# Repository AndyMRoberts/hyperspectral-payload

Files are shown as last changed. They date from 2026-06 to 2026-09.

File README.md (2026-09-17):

# Hyperspectral Payload

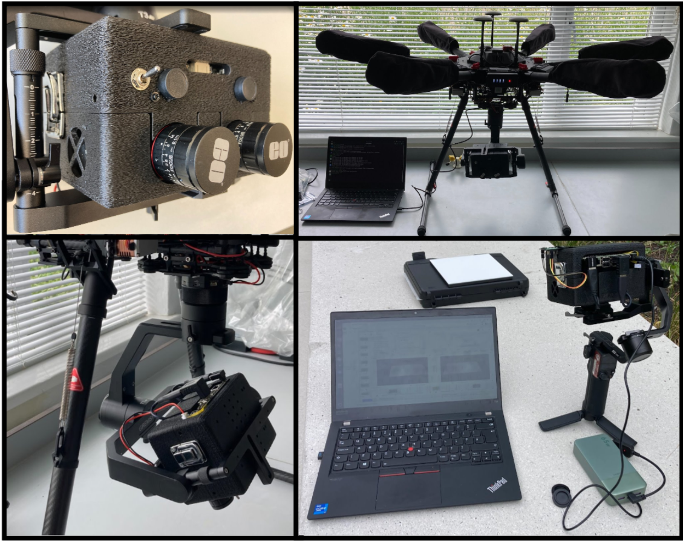
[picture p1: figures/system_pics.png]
System overview


# Folder Structure

```
hyperspectral-payload/
├── 3D_models/              CAD models (STL) for the payload enclosure and sensor mounts.
├── calibration_files/      Used by some of the test code in private_repo, not necessary for running but there as an example of the folder structure created during a run. 
├── figures/                Documentation images, including the system overview photo.
├── foxglove/               Foxglove Studio layout configs and generator for live ROS visualization.
├── private_repo/           Git submodule for development code
├── processing/             Offline Jupyter notebooks for post-run HSI data analysis.
└── ros2_ws/                Main ROS 2 workspace — onboard drivers, processing, and launch files.
    └── scripts/            Currently scripts for downloading and configuring extra ros2 nodes.
    └── src/
        ├── bringup/        Top-level launch files that start cameras, previews, and related nodes.
        │   └── hsi_bringup/
        ├── common/         Shared Python utilities used across HSI packages.
        │   └── hsi_python_utils/
        ├── controller/     System-level controller nodes for coordinating the platform.
        │   └── hsi_system_controller/
        ├── custom_msgs/    Custom ros2 messages e.g. hyperspectral data cube
        ├── monitoring/     Onboard power and memory usage monitoring.
        │   └── system_profiler/
        ├── processing/     Real-time image processing pipelines.
        │   ├── hsi_binned_preview_cpp/     Downsampled max/avg/colour previews for HSI streams.
        │   ├── radiometric_processing/       IN DEVELOPMENT: online fast radiometric processing in python
        │   ├── radiometric_processing_cpp/   IN DEVELOPMENT: online fast radiometric processing in cpp
        │   └── stereo_binned_preview_cpp/    Stereo rectification, disparity, and binned previews.
        └── sensors/        Hardware drivers for all payload sensors.
            ├── gps_monitor_cpp/              DFRobot USB GPS receiver — publishes NavSatFix.
            ├── hsi_camera_driver_cpp/        IMEC mosaic hyperspectral camera driver (VIS and NIR).
            ├── imu/                          IMU on the Waveshare stereo camera board (I2C).
            ├── spectrometer/                 AS7341 spectrometer — publishes spectral curves.
            └── stereo_camera/                IMX219 stereo camera — raw left/right image streams.
```

# ROS 2 workspace

## Intro

This repo is a working progress for the open source hyperspectral payload project, it includes all code and 3d prints necessary for reproducing and running the payload. Note that the system relies on having the specific MQ022HG-IM-SM4X4-VIS3 & MQ022HG-IM-SM5X5-NIR2 Ximea XiSpec hyperspectral sensors and IMEC API for grabbing/processing. 

### Dependencies
- IMEC API (provided with Ximea XiSpec camera purchase)
- ROS2 Humble distro (https://docs.ros.org/en/humble/index.html)
- Tested on Jetson Orin Nano running Jetpack 6.2.1

### Setup
1. Clone repo to the Jetson Nano and install dependencies.
1. From \ros2_ws run:

```
source /opt/ros/humble/setup.bash
colcon build
source install/setup.sh
```

1. 3D print case parts and add screw inserts x4.
1. Install hardware into case.
1. Connect Jetson to the same wifi network as the remote PC, can be a wifi hotspot generated from a laptop.
1. Import the foxglove layout file (master_layout.json) to either the web or desktop version of the foxglove UI on the remote PC, connect to the IP address of the Jetson. 
1. SSH to the Jetson and from \ros2_ws launch system with full system launch command, this will also launch the foxglove bridge to allow communication with foxglove UI over the network.

'ros2 launch hsi_bringup full_system.launch.py run_name:=default_run_name acquisition_rate_hz:=20.0 throttled_rate_hz:=20.0'

### General Overview
- SSH onto the device from field laptop.
- Use a launch file to launch the desired nodes with the desired settings.
- Via the Foxglove interface you can view the output data and send conrol messages to the system, such as for recording reference images, initiating timelapses, stopping, and shutting down. 
- Reference images are collected first using the foxglove interface. 
- Once ready a timelapse can be started, this records the hyperspectral images using the imec_api, and all other sensor data via a rosbag of the relevant topics.
- Once done, stop the recording via the foxglove interface stop button(rosbag will be corrupt if not shutdown properly), then shutdown the ros system from the UI, as well as killing any remaining nodes with 'ctrl + c' from the launch terminal. 
- Safely shutdown the jetson using 'sudo shutdown now'.

### Configurations
- Rosbag recording topics: in order to reduce memory usage the rosbag topic list can be shortened via the exclusion list in camera_commands_controller.py.
- Nodes: nodes can be excluded from launch if not required via the hsi_bringup full_system.launch.py file.
- 

### Example Launch Commands
```
# Run full system with legacy stereo (not issac argus node), with only left camera recording, no live radiometric processing, hsi cameras acquiring at 20hz, rosbag saving at 20Hz:
ros2 launch hsi_bringup full_system.launch.py run_name:=run_name_here acquisition_rate_hz:=20.0 throttled_rate_hz:=20.0 use_legacy_stereo:=True single_stereo_mode:=True enable_online_radiometric_proc:=False

# Same as above but with under development isaac argus node running for the stereo recording and processing:
ros2 launch hsi_bringup full_system.launch.py run_name:=test acquisition_rate_hz:=20.0 throttled_rate_hz:=20.0 enable_online_radiometric_proc:=False

# For runnign stereo cameras only:
ros2 launch hsi_bringup stereo_only.launch.py run_name:=stereo_rate_testing use_legacy_stereo:=True single_stereo_mode:=True

```

### Data Collection Procedure

From the foxglove UI you need to set the integration times, and record calibration images using the buttons and message send options. An example of the interface is shown below:

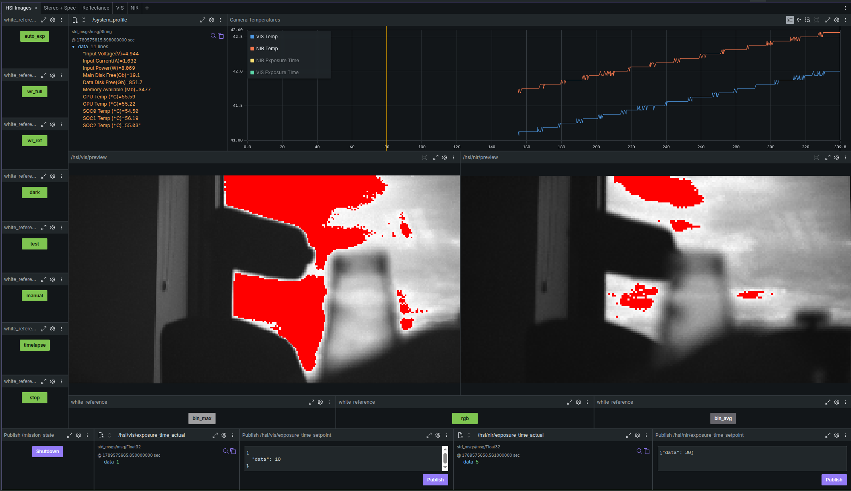
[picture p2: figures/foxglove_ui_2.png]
Foxglove UI


The visible image is in the left panel with nir in the right. The camera sensor temperatures are displayed in the top right panel, these should be stable before recording a session to prevent thermal drift effects in the sensors. The other_sensors tab will show the RGB stereo images and resulting depth image, as well as other sensor outputs like gps. 

1. Remove lens caps set F#, focus with the hyperspectral cameras, higher F#'s allow a greater Field Of View and hence more reliable imaging. 

1. The buttons down the left side are roughly followed from top to bottom:
- auto_exp - this will "reduce" the exposure/integration times of both sensors until no overexposure is imaged, the hsi image panels will show a grayscale image with red for overexposure to check. The exposure can be set manually using the data send panels along the bottom, by changing the int value after {"data": 10} and clicking the publish button. 
- wr_full - records a non-uniformity white reference in which the white reference panel should fill the full image. 
- wr_ref - records a reference white reference, an image that has the white reference in view but does not fill the full sensor. 
- dark - records a dark reference image. Lens caps should be placed on the sensors before taking this.
- test - records a test image that will be saved in the context folder. 
- manual - records a manual image that will be saved in the timelapse folder but will be titled "manual_#.raw".
- timelapse - triggers the timelapse recording at the configuration set at launch. 
- stop - stops the timelapse recording. 
- shutdown - triggers a graceful shutdown of the system. 

### Post Processing 

Once a run has been completed the raw hyperpectral images can be radiometrically processed and the rosbag unpacked using post_run_data_processing.ipynb.

# Other

## Build

From /ros2_ws directory:

```bash
source /opt/ros/humble/setup.bash
colcon build --symlink-install
source install/setup.bash
```

### Serial port permissions

The GPS receiver connects over USB serial (default `/dev/ttyACM0`). Without access to that device, `gps_monitor_cpp` fails with `open serial port: Permission denied`.

Do **not** run the node with `sudo` — that breaks ROS networking. Add your user to the `dialout` group instead (requires admin/sudo once):

```bash
sudo usermod -aG dialout $USER
```

Log out and log back in (or reboot), then verify:

```bash
groups                    # should list dialout
ls -la /dev/ttyACM0
ros2 run gps_monitor_cpp gps_monitor
```

To test in the current shell without logging out:

```bash
newgrp dialout
ros2 run gps_monitor_cpp gps_monitor
```

If you do not have sudo access, ask a system administrator to run `sudo usermod -aG dialout <username>` for you.

## GPS monitor

Publishes `sensor_msgs/NavSatFix` on `/sensors/gps` from the DFRobot USB GPS receiver:

```bash
source install/setup.bash
ros2 run gps_monitor_cpp gps_monitor
```

Override the serial port if needed:

```bash
ros2 run gps_monitor_cpp gps_monitor --ros-args -p serial_port:=/dev/ttyACM0
```

To print raw parsed GPS data (via `printf`) and publish `NavSatFix` even without a satellite fix:

```bash
ros2 run gps_monitor_cpp gps_monitor --ros-args -p publish_invalid:=true
```

See [Serial port permissions](#serial-port-permissions) if the node cannot open the device.

# Waveshare IMX219-83 Stereo Camera and IMU

Required to run this on Jetson Orin Nano: 

`sudo /opt/nvidia/jetson-io/jetson-io.py`

and configure for "Configure Jetson 24pin CSI Connector" >> "Configure for IMX219 Dual"

Demo code can be downloaded to ros2_ws/src/sensors/stereo_camera

```
wget https://files.waveshare.com/upload/e/eb/D219-9dof.tar.gz
tar zxvf D219-9dof.tar.gz
```

Other support here: https://www.waveshare.com/wiki/IMX219-83_Stereo_Camera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

For IMU use,respectively connect the SDA and SCL pins of the camera to pins 3 and 5
on the Jetson Nano.

# Spectrometer

Installs
```
sudo apt-get update
sudo apt-get install python3-pip i2c-tools libgpiod-dev
pip3 install Adafruit-Blinka adafruit-circuitpython-as7341
sudo usermod -aG i2c $USER
```

For testing:
```
export JETSON_MODEL_NAME=JETSON_ORIN_NANO
python3 spectrometer_test.py
```

# IMU

On pins 3 and 5 IMU shows up as addres 0x68 on i2c_7
`sudo i2cdetect -y -r 7`

## IMEC mosaic Python API — `LoadOpticalSetup` ctypes fix

`post_run_data_processing.ipynb` (and any code that calls `HSI_MOSAIC.LoadOpticalSetup()`) can fail with:

```text
ArgumentError: argument 1: TypeError: wrong type
```

This is **not** a missing file or UTF-8 encoding problem. The C API takes `char const*`, but the Python wrapper declares `ctypes.c_wchar_p` (expects a `str`) while passing `filename.encode('utf-8')` (`bytes`). ctypes rejects the argument before the DLL reads the XML.

**Fix** in `/opt/imec/hsi-mosaic/python_apis/hsi_mosaic/hsi_mosaic_api.py` (around the `mosaicLoadOpticalSetup` binding, line 487):

```python
# Before (broken):
__api_dll.mosaicLoadOpticalSetup.argtypes = [ctypes.c_wchar_p, ctypes.POINTER(OpticalSetup)]

# After (matches LoadContext and char const*):
__api_dll.mosaicLoadOpticalSetup.argtypes = [ctypes.c_char_p, ctypes.POINTER(OpticalSetup)]
```

Leave the call unchanged:

```python
result = __api_dll.mosaicLoadOpticalSetup(filename.encode('utf-8'), ctypes.byref(optical_setup))
```

Restart the Jupyter kernel (or re-import `hsi_mosaic`) after editing. This patch is overwritten if the IME SDK is reinstalled or upgraded.

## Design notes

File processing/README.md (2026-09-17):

# Post-Processing Scripts

## post_run_data_processing.ipynb
- runs on jetson (required for ros environment for rosbag unpacking)
- uses HSI_MOSAIC api to radiometrically process the HSI images and outputs some inspected images (see below)

Example Output:
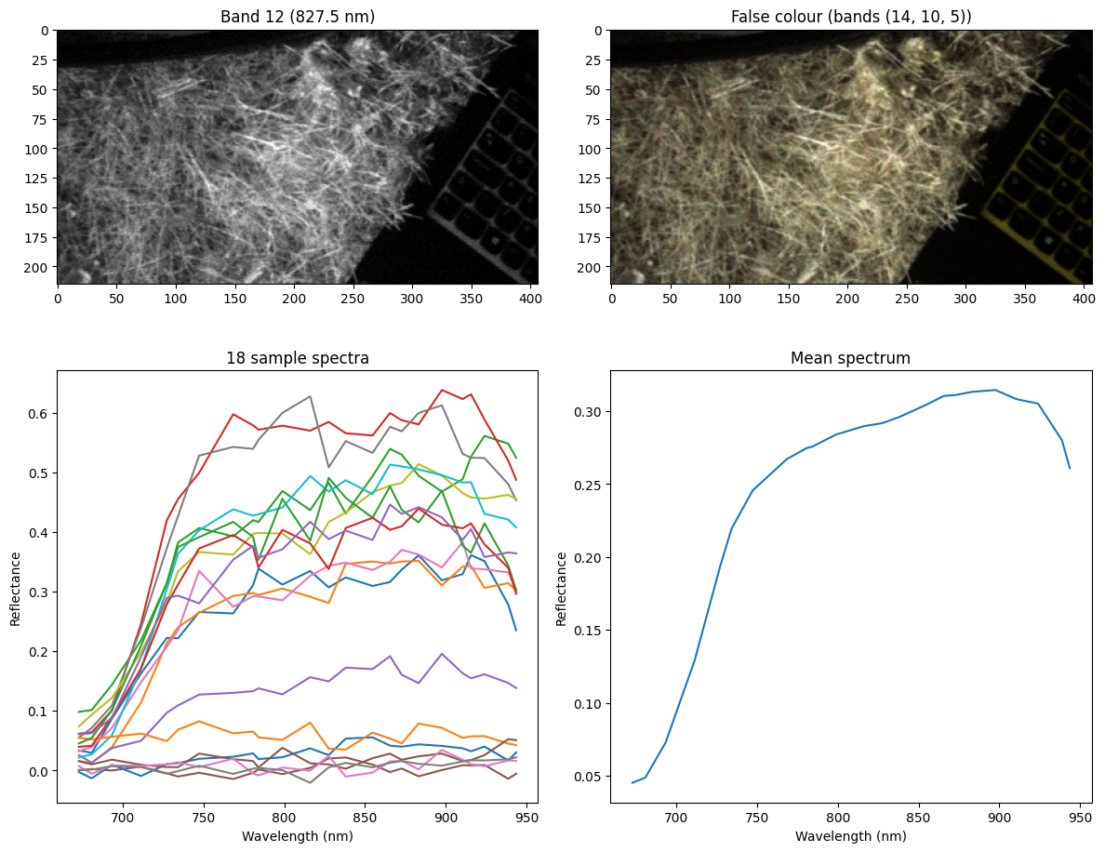
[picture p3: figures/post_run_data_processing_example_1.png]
Example Output


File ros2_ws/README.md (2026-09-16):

# ROS 2 workspace

## Todo
1. stereo camera needs hardware sync adding, then recalibration
2. Eventually if other sensors are required, change from HSI API to custom implementation in order to be able to record everything in a rosbag to be able to have synced data between HSI and everything else. 

## Clone

For others cloning this repo: after a normal clone, initialize submodules with:

```bash
git submodule update --init --recursive
```

Or clone in one step:

```bash
git clone --recurse-submodules <your-repo-url>
```

### USB_GPS_EN submodule: required `gps.h` patches

The `gps_monitor_cpp` package vendors [DFRobotdl/USB_GPS_EN](https://github.com/DFRobotdl/USB_GPS_EN) as a git submodule. After initializing submodules, apply these manual edits to:

`src/sensors/gps_monitor_cpp/include/USB_GPS_EN/gps.h`

Inside `parse_GpsDATA()`, in the `switch (i)` block:

1. **Comment out line 62** — the `buffer` variable is unused and triggers a compiler warning:

```c
// char buffer[12];
```

2. **Add `break;` statements** so that every `memcpy` in the switch ends with `break;` (lines 72 and 76 in the patched file; upstream is also missing breaks after the case 3 and case 5 `memcpy` calls). The corrected switch body should look like:

```c
switch(i){
  case 1:RST_Buffer(Save_Data.UTCTime);
    memcpy(Save_Data.UTCTime, subString, subStringNext - subString);break;
  case 2:RST_Buffer(usefullBuffer);
    memcpy(usefullBuffer, subString, subStringNext - subString);break;
  case 3:RST_Buffer(Save_Data.Slatitude);
    memcpy(Save_Data.Slatitude, subString, subStringNext - subString);break;
  case 4:RST_Buffer(Save_Data.N_S);
    memcpy(Save_Data.N_S, subString, subStringNext - subString);break;//获取 N/S
  case 5:RST_Buffer(Save_Data.Slongitude);
    memcpy(Save_Data.Slongitude, subString, subStringNext - subString);break;
  case 6:RST_Buffer(Save_Data.E_W);
    memcpy(Save_Data.E_W, subString, subStringNext - subString);break;//获取 E/W
  default:break;
}
```

Without these `break` statements, cases fall through and latitude/longitude parsing is corrupted.

### Serial port permissions

The GPS receiver connects over USB serial (default `/dev/ttyACM0`). Without access to that device, `gps_monitor_cpp` fails with `open serial port: Permission denied`.

Do **not** run the node with `sudo` — that breaks ROS networking. Add your user to the `dialout` group instead (requires admin/sudo once):

```bash
sudo usermod -aG dialout $USER
```

Log out and log back in (or reboot), then verify:

```bash
groups                    # should list dialout
ls -la /dev/ttyACM0
ros2 run gps_monitor_cpp gps_monitor
```

To test in the current shell without logging out:

```bash
newgrp dialout
ros2 run gps_monitor_cpp gps_monitor
```

If you do not have sudo access, ask a system administrator to run `sudo usermod -aG dialout <username>` for you.

## Build

From this directory:

```bash
source /opt/ros/$ROS_DISTRO/setup.bash
colcon build --symlink-install
source install/setup.bash
```

## GPS monitor

Publishes `sensor_msgs/NavSatFix` on `/sensors/gps` from the DFRobot USB GPS receiver:

```bash
source install/setup.bash
ros2 run gps_monitor_cpp gps_monitor
```

Override the serial port if needed:

```bash
ros2 run gps_monitor_cpp gps_monitor --ros-args -p serial_port:=/dev/ttyACM0
```

To print raw parsed GPS data (via `printf`) and publish `NavSatFix` even without a satellite fix:

```bash
ros2 run gps_monitor_cpp gps_monitor --ros-args -p publish_invalid:=true
```

See [Serial port permissions](#serial-port-permissions) if the node cannot open the device.

## Bringup: HSI cameras and binned preview

Launches the VIS and NIR `hsi_camera_driver_cpp` nodes and the `hsi_binned_preview_cpp` preview node:

```bash
source install/setup.bash
ros2 launch hsi_bringup hsi_cameras_with_binned_preview.launch.py
```

or for multicam
```bash
source install/setup.bash
ros2 launch hsi_bringup hsi_cameras_multicam_binned_preview.launch.py
```

# Waveshare IMX219-83 Stereo Camera and IMU

Required to run this on Jetson Orin Nano: 

`sudo /opt/nvidia/jetson-io/jetson-io.py`

and configure for "Configure Jetson 24pin CSI Connector" >> "Configure for IMX219 Dual"

## Isaac ROS Argus stereo (recommended)

Stereo capture is provided by [`isaac_ros_argus_camera`](https://github.com/NVIDIA-ISAAC-ROS/isaac_ros_argus_camera) (Isaac ROS **release-3.2**, matching JetPack 6.x / Humble) inside the Isaac Dev Docker container. Host bringup keeps HSI/GPS/etc. on the host and expects Argus to publish:

- `/sensors/stereo/left`
- `/sensors/stereo/right`

(`left/image_raw` / `right/image_raw` remapped by `argus_stereo.launch.py`)

### One-time host prerequisites (sudo)

Rootfs is small; Docker **and containerd** data must live on `/mnt/data` (Isaac pulls otherwise fill `/var/lib/containerd` on eMMC):

```bash
bash ros2_ws/scripts/setup_isaac_docker_prereqs.sh
```

Then **log out and back in** (or `newgrp docker`) and verify:

```bash
docker ps
git lfs version
df -h /
```

If the container fails with `unresolvable CDI devices nvidia.com/gpu=all`, `run_dev.sh` is patched to use `NVIDIA_VISIBLE_DEVICES=all`. Optional CDI generate:

```bash
sudo nvidia-ctk cdi generate --output=/etc/cdi/nvidia.yaml
```

Repos are already cloned under `ros2_ws/src/isaac_ros_common` and `ros2_ws/src/isaac_ros_argus_camera` (branch `release-3.2`). Host `colcon build` skips them via `COLCON_IGNORE` in those trees.

### Two-terminal workflow

**Terminal A — Isaac Docker (Argus):**

```bash
cd /home/hyper/hyperspectral_camera/ros2_ws
./scripts/run_isaac_dev.sh
# inside container only:
./scripts/build_isaac_argus.sh
source /opt/ros/humble/setup.bash
ros2 launch /workspaces/isaac_ros-dev/src/bringup/hsi_bringup/launch/argus_stereo.launch.py
```

Notes:
- `build_isaac_argus.sh` installs apt package `ros-humble-isaac-ros-argus-camera`.
- Do **not** `source install/setup.bash` inside the container — that tree was built on the host with paths under `/home/hyper/...`, which break under `/workspaces/...`.
- Launch the remapped file by **absolute path** (no need to colcon-build `hsi_bringup` in Docker).

**Terminal B — host (rest of system):**

```bash
cd /home/hyper/hyperspectral_camera/ros2_ws
source /opt/ros/humble/setup.bash
source install/setup.bash
ros2 launch hsi_bringup full_system.launch.py run_name:=test
# or stereo-focused:
ros2 launch hsi_bringup stereo_only.launch.py run_name:=test
```

By default `use_legacy_stereo:=false` so the host does **not** start the OpenCV `stereo_camera` node.

### Legacy OpenCV stereo fallback

```bash
ros2 launch hsi_bringup full_system.launch.py use_legacy_stereo:=true
```

### Camera daemon

If Argus fails to open the sensor:

```bash
sudo systemctl restart nvargus-daemon.service
```

---

## Legacy OpenCV stereo notes

Demo code can be downloaded to ros2_ws/src/sensors/stereo_camera

```
wget https://files.waveshare.com/upload/e/eb/D219-9dof.tar.gz
tar zxvf D219-9dof.tar.gz
```

Other support here: https://www.waveshare.com/wiki/IMX219-83_Stereo_Camera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

For IMU use,respectively connect the SDA and SCL pins of the camera to pins 3 and 5
on the Jetson Nano.

To fix image looking overly red (from link):
```
wget https://files.waveshare.com/upload/e/eb/Camera_overrides.tar.gz
tar zxvf Camera_overrides.tar.gz 
sudo cp camera_overrides.isp /var/nvidia/nvcam/settings/
sudo chmod 664 /var/nvidia/nvcam/settings/camera_overrides.isp
sudo chown root:root /var/nvidia/nvcam/settings/camera_overrides.isp
```

# Spectrometer

Installs
```
sudo apt-get update
sudo apt-get install python3-pip i2c-tools libgpiod-dev
pip3 install Adafruit-Blinka adafruit-circuitpython-as7341
sudo usermod -aG i2c $USER
```

For testing:
```
export JETSON_MODEL_NAME=JETSON_ORIN_NANO
python3 spectrometer_test.py
```

# IMU

On pins 3 and 5 IMU shows up as addres 0x68 on i2c_7
`sudo i2cdetect -y -r 7`

## IMEC mosaic Python API — `LoadOpticalSetup` ctypes fix

`post_run_data_processing.ipynb` (and any code that calls `HSI_MOSAIC.LoadOpticalSetup()`) can fail with:

```text
ArgumentError: argument 1: TypeError: wrong type
```

This is **not** a missing file or UTF-8 encoding problem. The C API takes `char const*`, but the Python wrapper declares `ctypes.c_wchar_p` (expects a `str`) while passing `filename.encode('utf-8')` (`bytes`). ctypes rejects the argument before the DLL reads the XML.

**Fix** in `/opt/imec/hsi-mosaic/python_apis/hsi_mosaic/hsi_mosaic_api.py` (around the `mosaicLoadOpticalSetup` binding, line 487):

```python
# Before (broken):
__api_dll.mosaicLoadOpticalSetup.argtypes = [ctypes.c_wchar_p, ctypes.POINTER(OpticalSetup)]

# After (matches LoadContext and char const*):
__api_dll.mosaicLoadOpticalSetup.argtypes = [ctypes.c_char_p, ctypes.POINTER(OpticalSetup)]
```

Leave the call unchanged:

```python
result = __api_dll.mosaicLoadOpticalSetup(filename.encode('utf-8'), ctypes.byref(optical_setup))
```

Restart the Jupyter kernel (or re-import `hsi_mosaic`) after editing. This patch is overwritten if the IME SDK is reinstalled or upgraded.

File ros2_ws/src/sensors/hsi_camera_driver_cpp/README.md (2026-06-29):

# hsi_camera_driver_cpp

ROS 2 Humble C++ node for HSI camera acquisition using the imec Camera API.

## Build

```bash
cd /home/hyper/hyperspectral_camera/ros2_ws
colcon build --packages-select hsi_camera_driver_cpp --symlink-install
source install/setup.bash
```

## Run

### Basic run

```bash
ros2 run hsi_camera_driver_cpp hsi_camera_node
```

### Run with parameters (free-run)

```bash
ros2 run hsi_camera_driver_cpp hsi_camera_node \
  --ros-args \
  -p free_run:=true \
  -p timelapse_hz:=1.0 \
  -p rate_hz:=20.0 \
  -p device_name:=nir \
  -p exposure_time_ms:=20.0 \
  -p gain:=1.0 \
  -p test_frame_count:=-1 \
  -p run_name_path:=/mnt/data/timelapses/20260101_120000_test_commands
```

### Run with parameters (fixed-rate software trigger)

```bash
ros2 run hsi_camera_driver_cpp hsi_camera_node \
  --ros-args \
  -p free_run:=false \
  -p rate_hz:=5.0 \
  -p device_name:=nir \
  -p exposure_time_ms:=10.0 \
  -p gain:=1.0 \
  -p test_frame_count:=100

```

## Parameters

- `free_run` (`bool`, default: `true`): free-running acquisition mode.
- `rate_hz` (`double`, default: `20.0`): loop rate used when `free_run:=false`.
- `device_name` (`string`, default: `""`): camera selector (`vis`, `nir`, or empty for first detected camera).
- `exposure_time_ms` (`double`, default: `10.0`): camera exposure time.
- `gain` (`double`, default: `1.0`): camera gain.
- `test_frame_count` (`int`, default: `-1`): if non-negative, stops after that many frames and prints elapsed time/FPS.
- `camera_start_delay_ms` (`int`, default: `0`): if positive, sleeps that many milliseconds immediately before `cameraStart()` (useful to stagger two nodes on the same USB bus).

## Launch both cameras

```bash
ros2 launch hsi_camera_driver_cpp hsi_dual_camera.launch.py
```

This launch file starts two node instances:
- VIS camera node with `device_name:=vis` and `camera_start_delay_ms:=0`
- NIR camera node with `device_name:=nir` and `camera_start_delay_ms:=2500` (starts streaming slightly later to reduce USB contention)

## Published Topics

- `/hsi/<device_name>/raw_image` (`sensor_msgs/msg/Image`)
- `/hsi/<device_name>/raw_metadata` (`std_msgs/msg/String`)
- `/hsi/<device_name>/temp` (`std_msgs/msg/Float32`)

## Notes

- The node links against imec SDK libraries in `/opt/imec/hsi-mosaic/bin`.
- If your shell cannot find those shared libraries at runtime, set:

```bash
export LD_LIBRARY_PATH=/opt/imec/hsi-mosaic/bin:$LD_LIBRARY_PATH
```

- once publishing enabled the rate is throttled to about 25Hz

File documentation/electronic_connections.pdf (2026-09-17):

## Electronics

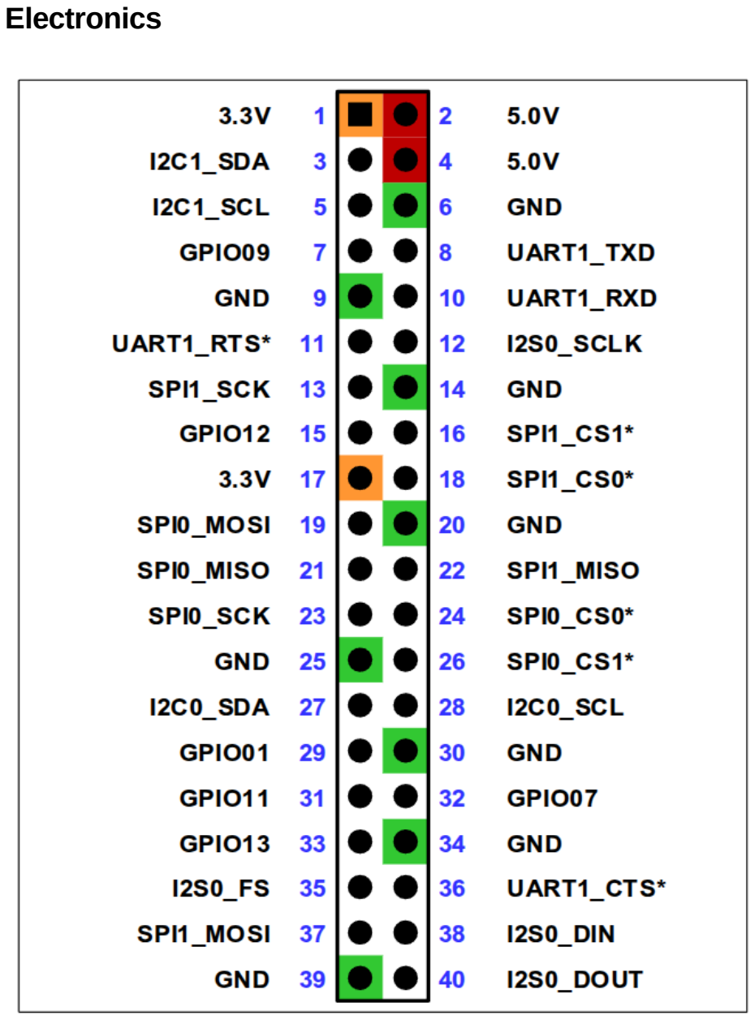
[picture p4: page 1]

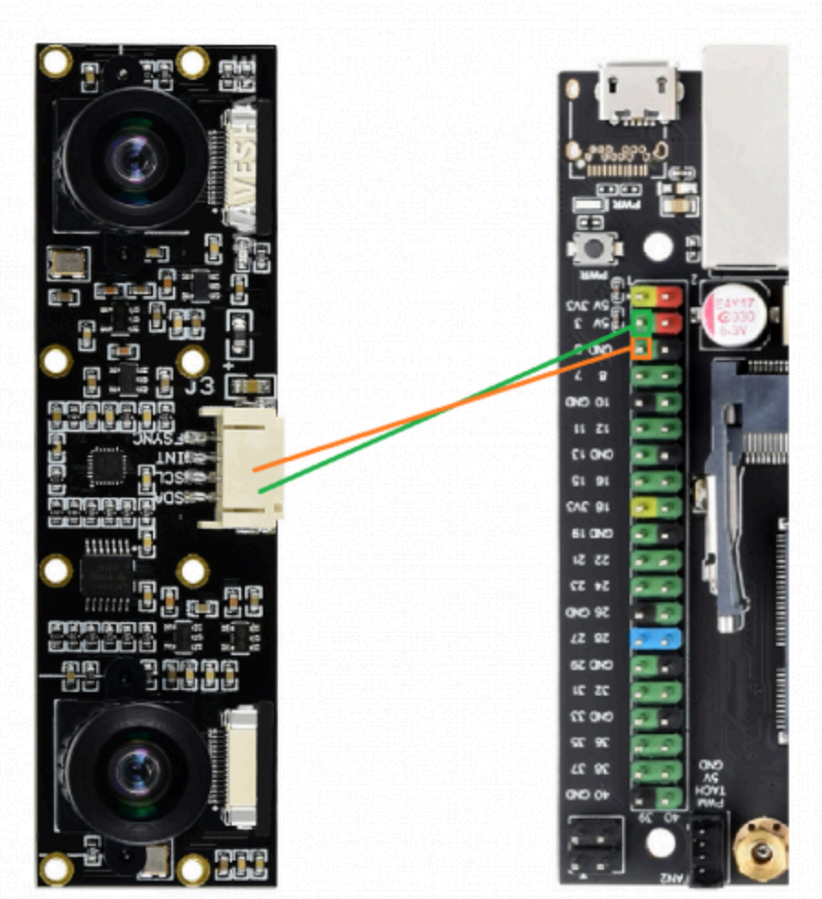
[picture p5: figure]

Mikroe: https://www.mikroe.com/spectrometer-click?srsltid=AfmBOoq2WCiolWs3EBrGVhS9cOvY8pOKp8dyzJ-nhC9IxcjtML4PU1Ps (https://www.mikroe.com/spectrometer-click)

Pin | Name | Notes | Use in Hyper
1 | 3.3V | Power (3.3V rail) | mikroe +
2 | 5.0V | Power (5V rail) | fan + (white)
3 | I2C1_SDA | I2C bus 1 data | IMU Stereo SDA (yellow)
4 | 5.0V | Power (5V rail)
5 | I2C1_SCL | I2C bus 1 clock | IMU Stereo SCL (blue)
6 | GND | Ground | fan - (black)

Pin | Name | Notes | Use in Hyper
7 | GPIO09 | General purpose I/O
8 | UART1_TXD | UART transmit
9 | GND | Ground | mikroe -
10 | UART1_RXD | UART receive
11 | UART1_RTS* | UART flow control
12 | I2S0_SCLK | Audio I2S clock
13 | SPI1_SCK | SPI1 clock
14 | GND | Ground
15 | GPIO12 | General purpose I/O
16 | SPI1_CS1* | SPI1 chip select
17 | 3.3V | Power (3.3V rail)
18 | SPI1_CS0* | SPI1 chip select
19 | SPI0_MOSI | SPI0 master out
20 | GND | Ground
21 | SPI0_MISO | SPI0 master in
22 | SPI1_MISO | SPI1 master in
23 | SPI0_SCK | SPI0 clock
24 | SPI0_CS0* | SPI0 chip select
25 | GND | Ground
26 | SPI0_CS1* | SPI0 chip select
27 | I2C0_SDA | I2C bus 0 data | mikroe data
28 | I2C0_SCL | I2C bus 0 clock | mikroe data
29 | GPIO01 | General purpose I/O
30 | GND | Ground
31 | GPIO11 | General purpose I/O
32 | GPIO07 | General purpose I/O
33 | GPIO13 | General purpose I/O
34 | GND | Ground
35 | I2S0_FS | Audio I2S frame sync
36 | UART1_CTS* | UART flow control
37 | SPI1_MOSI | SPI1 master out
38 | I2S0_DIN | Audio input
39 | GND | Ground
40 | I2S0_DOUT | Audio output

## IMU I2C Issue:

https://nvidia-jetson.piveral.com/jetson-orin-nano/no-device-getting-detected-i2c-jetson-orinnano-devkit/ (https://nvidia-jetson.piveral.com/jetson-orin-nano/no-device-getting-detected-i2c-jetson-orin-nano-devkit/)

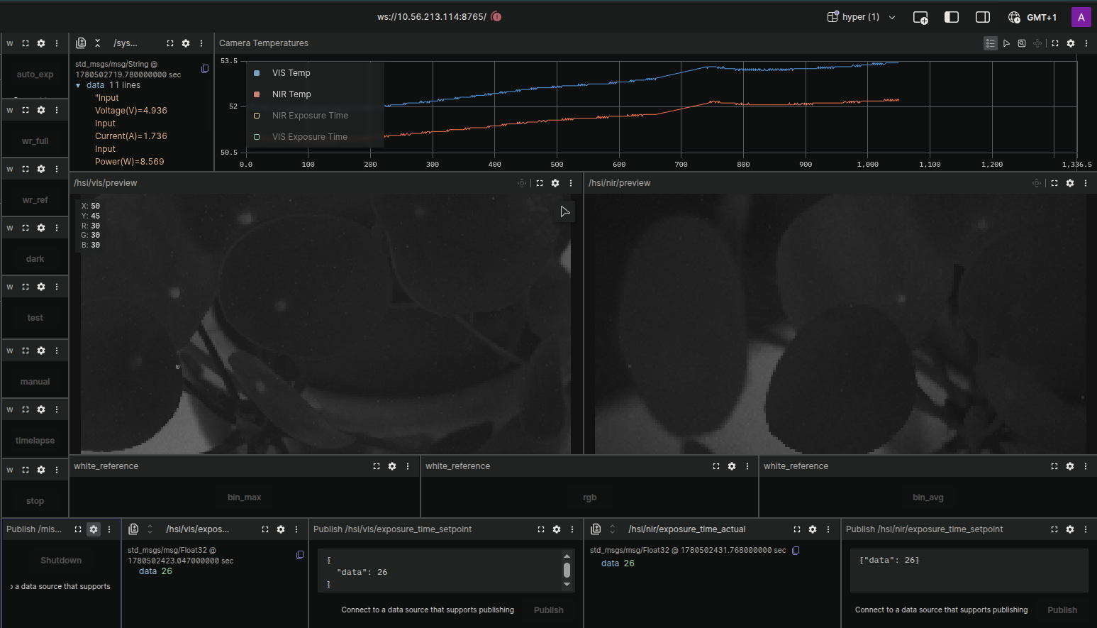
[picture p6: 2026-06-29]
figures/UI.png

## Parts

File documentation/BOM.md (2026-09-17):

| Item # | Part Name | Description | Part Number | Quantity | Supplier | Cost (GBP) | Link |
| --- | --- | --- | --- | --- | --- | --- | --- |
| 1 | Lexar M.2 (2280) 1 TB Internal SSD | Hard Drive 1TB NVME SSD | 267-6408 | 1 | RS | 114.60 | https://uk.rs-online.com/web/p/hard-drives/2676408 |
| 2 | Nvidia Jetson Orin Nano | Single Board Computer (7-25W power, 9-20V) | 264-7384 | 1 | RS | 259.01 | https://uk.rs-online.com/web/p/processor-development-tools/2647384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 |
| 4 | DFRobot TEL0138 GPS Receiver | GPS | 247-3251 | 1 | RS | 11.53 | https://uk.rs-online.com/web/p/gnss-gps-modules/2473251<br>https://wiki.dfrobot.com/USB_GPS_Receiver_SKU_TEL0137#USB%20GPS%20Receiver%20(2m%20Extension%20Cable) |
| 5 | High-Precision Spectral Colour Sensor (AS7341) | spectrometer sensor VIS - 350nm to 1000nm. | SKU: WAV-19564 | 1 | PiHut | 19.20 | https://thepihut.com/products/high-precision-spectral-colour-sensor-as7341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 |
| 8 | StarTech.com USB 3.0, Male USB A to Male Micro USB B, 5Gbps, 150mm | Short camera connectors (Note: longer cables are actually better and cause less stress on the camera connection) | 186-3203 | 2 | RS | 20.88 | https://uk.rs-online.com/web/p/usb-cables/1863203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 |
| 10 | RS PRO Toggle Switch, Panel Mount, (On)-Off-(On), DPDT, Solder Terminal | Power switch Dpdt | 734-7044 | 1 | RS | 4.03 | https://uk.rs-online.com/web/p/toggle-switches/7347044 |
| 12 | Kingston 64 GB MicroSD Micro SD Card, Class 10, UHS-I | SD card | 186-3203 | 1 | RS | 8.84 | https://uk.rs-online.com/web/p/sd-cards/1958342 |
| 13 | TP-Link M7000 Unlocked LTE Cat4 4G Portable Travel Wi-Fi | hotspot (if laptop not able to generate hotspot) | 771/8216 | 1 | Argos | 32.99 | https://www.argos.co.uk/product/7718216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 |
| 16 | JST-XH 2.54mm Pitch Connector Kit - 560 Piece Kit | Connector Kit (for connection to drone power supply) | ADA4423 | 1 | Pi Hut | 24.00 | https://thepihut.com/products/jst-xh-2-54mm-pitch-connector-kit-560-piece-kit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 |
| 17 | USB C to A right angle adaptor | Camera connector cable right angle adaptor for reduced footprint | ASIN: B0BLMWH15B | 1 | Amazon | 4.99 | https://amzn.eu/d/07cmYC8u |
| 18 | USB A to A right angle adaptor | Camera connector cable right angle adaptor for reduced footprint | ASIN: B079CC2SGB | 1 | Amazon | 4.99 | https://amzn.eu/d/05zjlcif |

# Optionals

Optional to connect to DJI M600 Drone

| **Item** | **Quantity** | **Part Number** | **Description** | **Serial Number** | **Supplier** | **Cost (GBP)** | **Link** |
| --- | --- | --- | --- | --- | --- | --- | --- |
| Gremsy T3V3 to M600 CAN Cable | 1 | - | Gremsy- Cable for DJI FC (A3, N3) | NA | 3DXR | 25.00 | https://www.3dxr.co.uk/products/gremsy-cable-for-dji-fc-a3-n3 |
| GREMSY T3V3 Gimbal | 1 | - | Drone Gimbal | NA | 3DXR | 1749.00 | https://www.3dxr.co.uk/camera-fpv-c57/gimbals-c214/gremsy-t3v3-p3835** |

Optional for handheld gimbal use

| Item | Quantity | Part Number | Description | Serial Number | Supplier | Cost (GBP) | Link |
| --- | --- | --- | --- | --- | --- | --- | --- |
| DJI RS 3 Mini | 1 | - | Gimbal Handheld | NA | DJI Store UK | 219 | https://store.dji.com/uk/product/dji-rs-3-mini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 |

Optional for running with external battery power supply

| **Item** | **Quantity** | **Part Number**  | **Description** | **Serial Number** | **Supplier** | **Cost (GBP)** | **Link** |
| --- | --- | --- | --- | --- | --- | --- | --- |
| USB C PD to DC Power Converter Cable | 1 | ASIN: B0GD716J8J | USB C PD to DC Power Converter Cable Charger Adapter 5V,9V,12V,15V,20V Adjustable Voltage Right Angle Type C to DC 5.5x2.1mm plug Universal Power Supply Lead with 10 DC Conversion Heads for Ro | NA | Amazon | 7.99 | https://amzn.eu/d/02FgYsyW |
| PD Power Bank 65W 20KmAh (green) | 1 | ASIN: B0FWR98WX5 | JUOVI Power Bank 65W 20000mAh Laptop Portable Charger, PD QC Fast Charging with 4 USB Ports, External Battery Pack for MacBook iPad Tablet Phone Steam Deck and More (Black) | NA | Amazon | 36.99 | https://amzn.eu/d/0aSAl5yZ |

Printing Material Options

| **Item** | **Quantity** | **Part Number** | **Description** | **Serial Number** | **Supplier** | **Cost** | **Link** |
| --- | --- | --- | --- | --- | --- | --- | --- |
| Black PETG Filament 1Kg | 1 (1Kg) | - | ELEGOO Rapid PETG Filament 1.75mm Black 1KG, High Speed Up to 600mm/s 3D Printer Filament Dimensional Accuracy +/- 0.02 mm, 1kg Cardboard Spool(2.2lbs) Fits for Most FDM 3D Printers | NA | Amazon | 12.99 | https://amzn.eu/d/08BM6OOt |
| Black PLA Filament 2Kg  | 1 (2Kg) | - | eSUN PLA Filament 1.75mm, PLA Basic 3D Printer Filament Dimensional Accuracy +/- 0.05mm, 1KG per Spool, 2 Spools 3D Printing Filament,Black and Black | NA | Amazon | 17.02 | https://amzn.eu/d/07CZfh9e |

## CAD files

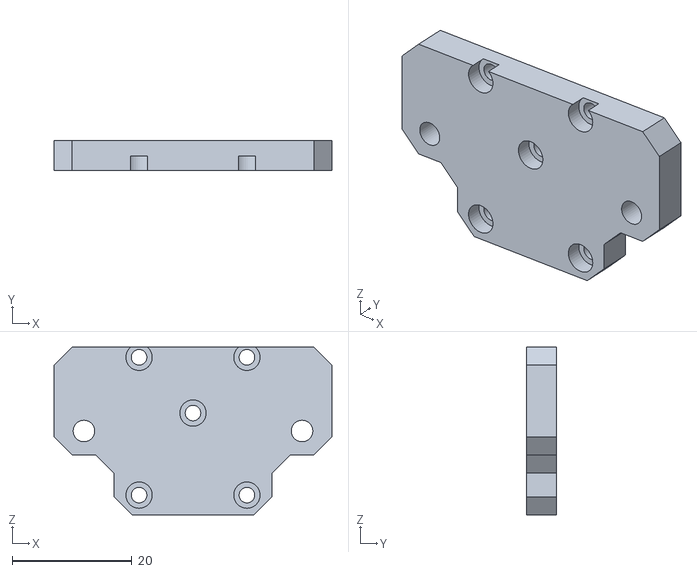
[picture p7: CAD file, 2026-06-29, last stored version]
3D_models/v3/camera_base_adaptor.STL
46.4 x 5.00 x 28.0

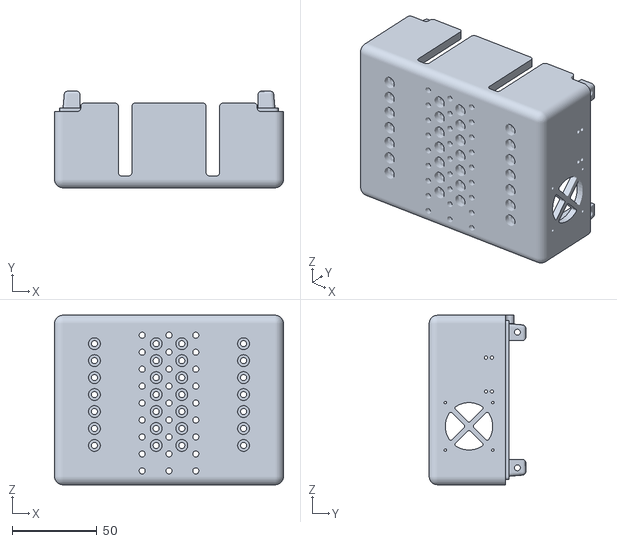
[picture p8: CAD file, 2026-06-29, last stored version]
3D_models/v3/camera_base.STL
135.0 x 57.0 x 100.0

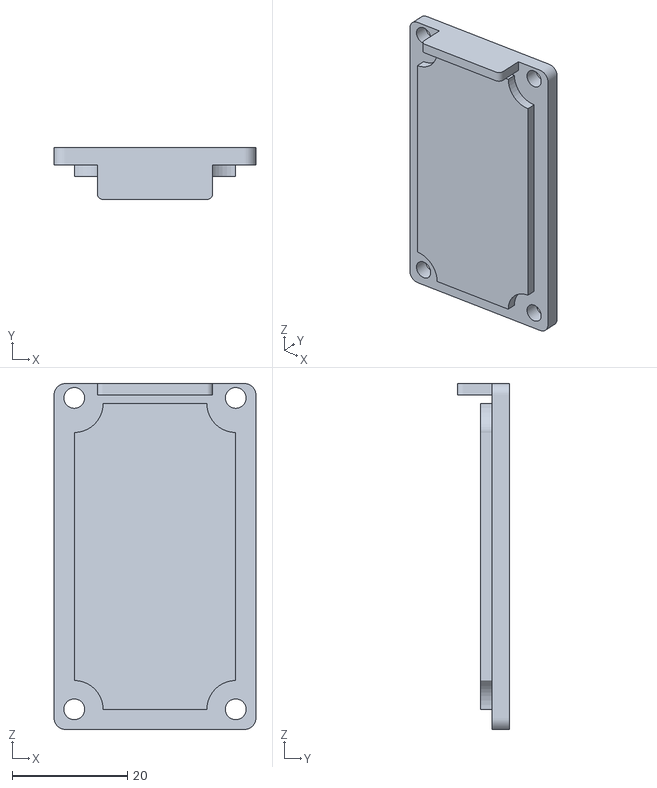
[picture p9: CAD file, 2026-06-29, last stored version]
3D_models/v3/spectrometer_lid.STL
35.0 x 9.00 x 60.0

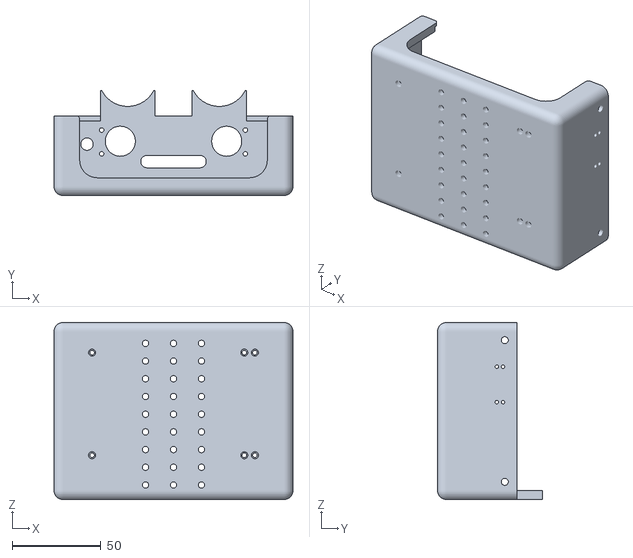
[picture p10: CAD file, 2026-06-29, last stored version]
3D_models/v3/jetson_base.STL
135.0 x 59.3 x 100.0

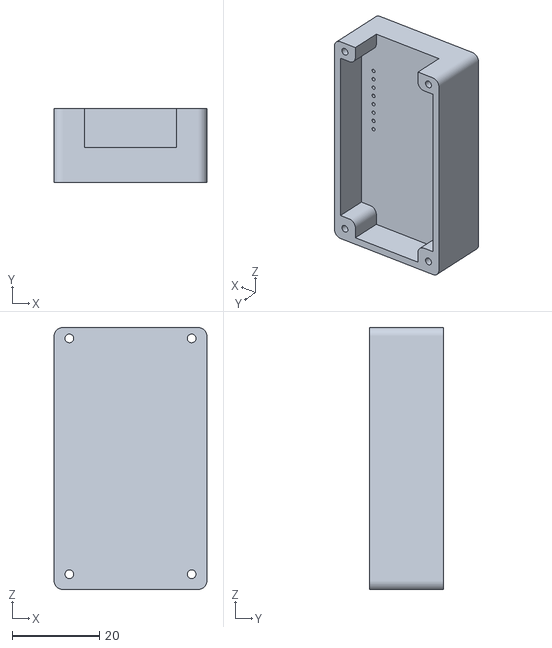
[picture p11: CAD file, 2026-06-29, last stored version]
3D_models/v3/spectrometer_base.STL
35.0 x 17.0 x 60.0

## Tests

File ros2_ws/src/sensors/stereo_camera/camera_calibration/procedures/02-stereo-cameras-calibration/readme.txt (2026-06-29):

#Build:
$mkdir build
$cd build
$sudo cmake ..
$sudo make

#Run:
$./stereo_calibration -w=9 -h=6 -s=35 ../images/stereo_calib.xml

#RES
see the in/extrinsics results in "cal_results" folder, copyt them into your own project folder

Results: 1280x720
31 pairs have been successfully detected.
Running stereo calibration ...
done with RMS error=4.92013
average epipolar err = 6.49025

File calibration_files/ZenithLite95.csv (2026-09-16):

Wavelength (nm) | Reflectance Factor (%)
250 | 94.165145
251 | 94.381093
252 | 94.614658
253 | 94.757922
254 | 94.916205
255 | 95.049609
256 | 95.144948
257 | 95.21169
258 | 95.316506
259 | 95.432622
260 | 95.485347
261 | 95.529111
262 | 95.491885
263 | 95.524646
264 | 95.51966
265 | 95.564062
266 | 95.645518
267 | 95.650304
268 | 95.710884
269 | 95.632981
270 | 95.61063
271 | 95.666888
272 | 95.66781
273 | 95.585423
274 | 95.637673
275 | 95.696806
276 | 95.708528
277 | 95.665346
278 | 95.790005
279 | 95.799461
280 | 95.792142
281 | 95.865834
282 | 95.943205
283 | 95.973412
284 | 95.98388
285 | 95.995208
286 | 96.055026
287 | 96.086864
288 | 96.105025
289 | 96.078125
290 | 96.199743
291 | 96.229646
292 | 96.278165
293 | 96.417929
294 | 96.364976
295 | 96.417165
296 | 96.352996
297 | 96.542379
298 | 96.551343
299 | 96.380167
300 | 96.476465
301 | 96.466129
302 | 96.544264
303 | 96.669838
304 | 96.57398
305 | 96.571293
306 | 96.615039
307 | 96.644188
308 | 96.580139
309 | 96.792441
310 | 96.516958
311 | 96.605255
312 | 96.567223
313 | 96.677125
314 | 96.705386
315 | 96.525105
316 | 96.6631
317 | 96.483614
318 | 96.545648
319 | 96.352937
320 | 96.67726
321 | 96.463525
322 | 96.388158
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

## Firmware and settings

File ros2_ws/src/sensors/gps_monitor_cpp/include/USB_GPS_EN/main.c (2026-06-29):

#include "com.h"
#include "gps.h"


int fd;
char read_buffer[BUFFER_SIZE];
int read_buffer_size, now;


int main()
{
  
  //打开串口
  fd = open_port("/dev/ttyACM0");
  //设置串口
  if(set_com_config(fd, 115200, 8, 'N', 1) < 0) //配置串口 
  { 
    perror("set_com_config"); 
    return 1; 
  }
  while (1) {
    memset(read_buffer,0, BUFFER_SIZE);
    read_buffer_size= read_Buffer(fd, read_buffer);
    if(read_buffer_size > 0){
      //printf("[%d],[%s]\n", read_buffer_size, read_buffer);
      read_GPS_Data(read_buffer);
      parse_GpsDATA();
      if(Save_Data.ParseData_Flag == 1 && Save_Data.Usefull_Flag ==1){
        print_Save();
        Save_Data.Usefull_Flag=0;
        Save_Data.ParseData_Flag=0;
      }else{
        printf("Invalid GPS data\n");
      }
    }
  }
  close(fd);
  return 1;
}

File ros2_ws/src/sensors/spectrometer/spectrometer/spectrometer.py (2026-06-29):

#!/usr/bin/env python3

import os

# Jetson.GPIO (used by Blinka) may fail board detection on newer JetPack unless
# this is set before `board` is imported. An existing shell export takes precedence.
os.environ.setdefault("JETSON_MODEL_NAME", "JETSON_ORIN_NANO")

import board
import busio
import rclpy
from adafruit_as7341 import AS7341
from rclpy.node import Node
from std_msgs.msg import Float32MultiArray, String


def _read_channel(getter) -> float:
    try:
        return float(getter())
    except Exception:
        return float("nan")


class SpectrometerNode(Node):
    def __init__(self) -> None:
        super().__init__("spectrometer")

        self.declare_parameter("rate_hz", 1.0)
        self.declare_parameter("mission_state_topic", "/mission_state")
        self.declare_parameter("output_topic", "/sensors/spectrometer")

        rate_hz = float(self.get_parameter("rate_hz").value)
        if rate_hz <= 0.0:
            rate_hz = 1.0
            self.get_logger().warn("rate_hz must be > 0; using 10.0 Hz")

        output_topic = str(self.get_parameter("output_topic").value)
        mission_state_topic = str(self.get_parameter("mission_state_topic").value)

        self._mission_shutdown_pending = False

        i2c = busio.I2C(board.SCL_1, board.SDA_1)
        self._sensor = AS7341(i2c)

        self._publisher = self.create_publisher(Float32MultiArray, output_topic, 10)
        self._timer = self.create_timer(1.0 / rate_hz, self._on_timer)
        self._mission_sub = self.create_subscription(
            String, mission_state_topic, self._on_mission_state, 10
        )

        self.get_logger().info(f"Publishing spectrometer readings on {output_topic}")

    def _read_spectrum(self) -> list[float]:
        sensor = self._sensor
        return [
            _read_channel(lambda: sensor.channel_415nm),
            _read_channel(lambda: sensor.channel_445nm),
            _read_channel(lambda: sensor.channel_480nm),
            _read_channel(lambda: sensor.channel_515nm),
            _read_channel(lambda: sensor.channel_555nm),
            _read_channel(lambda: sensor.channel_590nm),
            _read_channel(lambda: sensor.channel_630nm),
            _read_channel(lambda: sensor.channel_680nm),
            _read_channel(lambda: sensor.channel_nir),
            _read_channel(lambda: sensor.channel_clear),
        ]

    def _on_timer(self) -> None:
        if self._mission_shutdown_pending:
            return

        msg = Float32MultiArray()
        msg.data = self._read_spectrum()
        self._publisher.publish(msg)

    def _on_mission_state(self, msg: String) -> None:
        if msg.data.strip().lower() != "shutdown":
            return
        if self._mission_shutdown_pending:
            return

        self._mission_shutdown_pending = True
        self.get_logger().info("mission_state shutdown - exiting spectrometer cleanly")
        try:
            self.destroy_timer(self._timer)
        except (RuntimeError, ValueError):
            pass
        rclpy.shutdown()


def main(args=None) -> None:
    rclpy.init(args=args)
    node = SpectrometerNode()
    try:
        rclpy.spin(node)
    except KeyboardInterrupt:
        pass
    finally:
        node.destroy_node()
        rclpy.try_shutdown()


if __name__ == "__main__":
    main()

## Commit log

2026-09-16 merged latest version from private repo, added private-repo submodule, newest changes incorporate experimental fast radiometric processing, attempted isaac argus stereo node, calibration files,
    [ZenithLite95.csv]
2026-09-17 Added BOM, electronic_connections.pdf and solidworks files via git LFS.
    [camera_base.STL, camera_base_adaptor.STL, jetson_base.STL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]
